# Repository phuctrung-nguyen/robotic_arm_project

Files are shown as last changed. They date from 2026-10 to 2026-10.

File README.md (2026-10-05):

# 4-DOF RPRR Welding Robot — Robotics Course Project

Design, analysis and simulation of a 4-degree-of-freedom welding robot arm of type **R–P–R–R** (revolute – prismatic – revolute – revolute), covering the full pipeline from mechanical design, kinematics, dynamics, trajectory planning and controller design to simulation in ROS 2.

## Contents

| Folder | Content | Tools |
|---|---|---|
| [`solid_des`](solid_des) | 3D models of the links, assemblies, welding head, technical drawings | SolidWorks |
| [`mapler`](maple) | Derivation of the robot's differential equations of motion | Maple |
| [`trajectory`](trajectory) | Forward/inverse kinematics (DH), Jacobian, workspace, manipulability index, LSPB trajectories in joint space and Cartesian space, animation | Python |
| [`IDPD_simulink`](IDPD_simulink) | IDPD (Inverse Dynamics PD) trajectory-tracking controller | MATLAB / Simulink |
| [`sim_ros2`](sim_ros2) | URDF model, Gazebo + RViz simulation, per-joint position control using Gazebo's PID | ROS 2 Jazzy, Gazebo Harmonic |

## Robot parameters (DH)

| Joint | Type | d (m) | a (m) | α (°) | Limits |
|---|---|---|---|---|---|
| q1 | Revolute | 0.2175 | 0 | 0 | 0° → 360° |
| q2 | Prismatic | q2 | 0.25 | 90 | 0 → 0.225 m |
| q3 | Revolute (θ = q3 + 90°) | 0.105 | 0 | 90 | −90° → 135° |
| q4 | Revolute (welding torch) | 0.262 | 0 | 0 | 0° → 360° |

Fixed base d0 = 0.084 m. The welding torch tip is offset by (−68, 0, 126) mm from frame O4.

End-effector convention: the workspace (`main.py`) is computed for the **welding torch tip** (with the offset above); the welding trajectory, inverse kinematics, Simulink and the ROS 2 simulation are all computed for the **origin of frame O4** (q4 = 0).

**Forward kinematics** (origin of frame O4):

```
x = 0.25·cos q1 + 0.105·sin q1 + 0.262·cos q1·cos q3
y = 0.25·sin q1 − 0.105·cos q1 + 0.262·sin q1·cos q3
z = q2 + 0.262·sin q3 + 0.3015
```

**Inverse kinematics**:

```
q1 = atan2(0.105, √(x² + y² − 0.105²)) + atan2(y, x)
q3 = atan2(√(1 − D²), D),   D = (x·cos q1 + y·sin q1 − 0.25) / 0.262
q2 = z − 0.262·sin q3 − 0.3015
```

This model is consistent across the whole repo: the DH table (`config/dh_params.yaml`), the URDF in ROS 2, the Python trajectory scripts and the Gazebo control node.

## Welding cycle

Non-contact arc welding along a 0.2 m vertical segment BA. The Cartesian trajectory uses a trapezoidal velocity profile (LSPB) with a sampling period of 0.01 s.

| Point | Coordinates (m) | Joint variables (q1 rad, q2 m, q3 rad) |
|---|---|---|
| HOME | (0.1518, −0.2730, 0.7698) | (−0.7205, 0.2101, 1.4013) |
| B — weld start | (0.1589, −0.1543, 0.7782) | (−0.2768, 0.2205, 1.7822) |
| A — weld end | (0.1589, −0.1543, 0.5782) | (−0.2768, 0.0205, 1.7822) |

| Phase | Max velocity | Acceleration | End time |
|---|---|---|---|
| HOME → B | 0.05 m/s | 0.10 m/s² | 2.88 s |
| Dwell at B (arc ignition) | — | — | 3.38 s |
| B → A (welding) | 0.01 m/s | 0.05 m/s² | 23.58 s |
| Dwell at A (crater filling) | — | — | 24.58 s |
| A → HOME | 0.05 m/s | 0.10 m/s² | 29.60 s |

2961 reference points in total (`Cartesian_Waypoints.txt`). The corresponding joint trajectories are exported to Simulink (`Vitridat.mat`, `Vantocdat.mat`, `Giatocdat.mat`).

## Quick start

**Kinematics & trajectories (Python)**

```bash
cd 03_dong_hoc_quy_dao_python
pip install -r requirements.txt
python main.py            # workspace + manipulability -> data/ket_qua.png
python JointSpace.py      # joint trajectories + export Vitridat/Vantocdat/Giatocdat.mat for Simulink
python CartesianSpace.py  # Cartesian trajectory + export Cartesian_Waypoints.txt
python animation.py       # 3D animation of the robot following the trajectory
python -m src.run_simulation  # quick Jacobian check at a sample configuration
```

**IDPD controller (MATLAB)**: run `initialize.m` first to load the parameters, then open `controller_simulation.slx` and click Run. See the [README](04_bo_dieu_khien_IDPD_simulink/README.md).

**ROS 2 simulation**: see [05_mo_phong_ros2/README.md](05_mo_phong_ros2/README.md).

## License

[MIT](LICENSE)

## Results

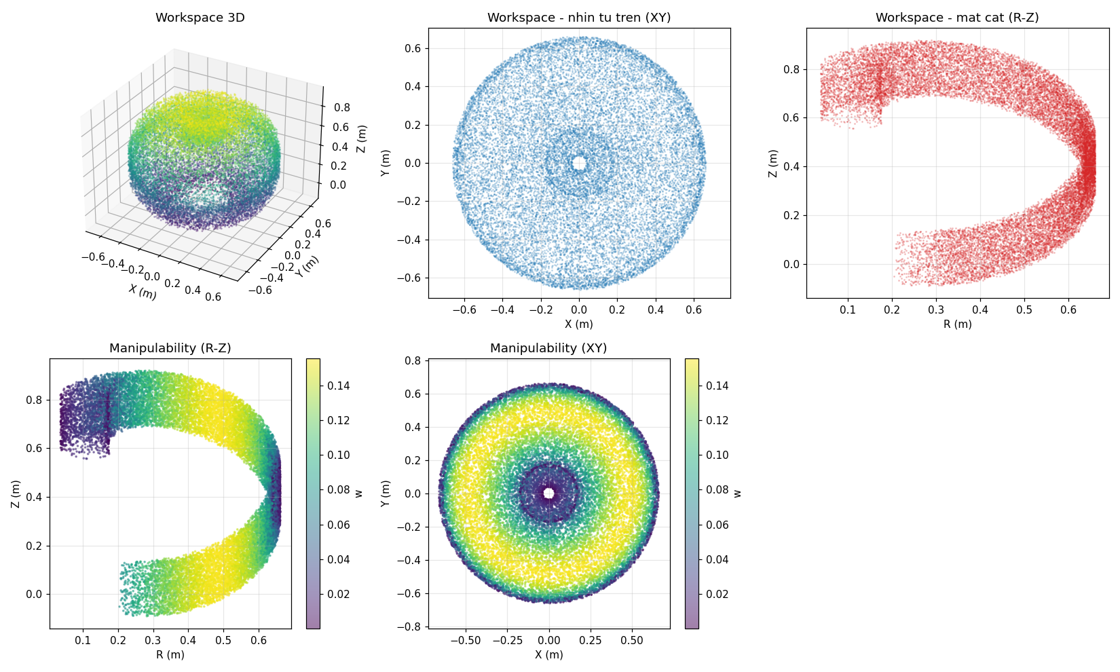
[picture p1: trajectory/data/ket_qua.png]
Workspace and manipulability


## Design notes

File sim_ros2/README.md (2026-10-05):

# Mô phỏng ROS 2 (Gazebo + RViz)

Workspace `rprr_ws` gồm 3 package:

```
rprr_ws/src/
├── robotic_arm_description/   # URDF/Xacro, mesh STL (xuất từ SolidWorks), cấu hình RViz
├── robotic_arm_bringup/       # Launch file, cấu hình Gazebo bridge
└── robotic_arm_control/       # trajectory_client.py: sinh quỹ đạo LSPB + động học ngược
```

## Yêu cầu

- Ubuntu 24.04 + ROS 2 Jazzy + Gazebo Harmonic (gz sim 8) — đã chạy thử trên cấu hình này
- **Không hỗ trợ ROS 2 Humble**: Humble đi kèm Gazebo Fortress, không nạp được các plugin `gz-sim-*` dùng trong
  `robotic_arm_gazebo.xacro` nên robot không có `/joint_states` và không điều khiển được
- `ros_gz_sim`, `ros_gz_bridge`, `robot_state_publisher`, `xacro`, `joint_state_publisher_gui`, `rviz2`
- Python: `numpy`

Cài các gói còn thiếu bằng `rosdep install --from-paths src --ignore-src -y` (trong `rprr_ws`).

## Build

```bash
cp -r rprr_ws ~/rprr_ws
cd ~/rprr_ws
colcon build
source install/setup.bash
```

## Chạy

Xem mô hình trên RViz (kéo thanh trượt để chỉnh từng khớp):

```bash
ros2 launch robotic_arm_bringup display.launch.py
```

Mô phỏng trên Gazebo + RViz:

```bash
ros2 launch robotic_arm_bringup gazebo.launch.py
```

Ở terminal thứ hai, chạy quỹ đạo hàn mẫu (Home → B → dừng → A → dừng → về Home):

```bash
cd ~/rprr_ws
source install/setup.bash
ros2 run robotic_arm_control trajectory_client.py
```

Quan sát Gazebo hoặc RViz, robot sẽ di chuyển theo đúng quỹ đạo đã thiết kế.

## Cách điều khiển trong Gazebo

`trajectory_client.py` tính trước quỹ đạo (LSPB trong không gian Cartesian + động học ngược) rồi cứ 10 ms phát
một điểm đặt xuống các topic `/q1_cmd_pos` ... `/q4_cmd_pos`. `ros_gz_bridge` chuyển các topic này sang Gazebo,
nơi mỗi khớp có một plugin `JointPositionController` (PID) riêng, khai báo trong
`robotic_arm_description/urdf/robotic_arm_gazebo.xacro`:

| Khớp | P | I | D |
|---|---|---|---|
| q1 | 12 | 0.2 | 1.0 |
| q2 | 120 | 80 | 20 |
| q3 | 300 | 200 | 4.0 |
| q4 | 15 | 0.3 | 1.5 |

Trạng thái khớp `/joint_states` do plugin `JointStatePublisher` của Gazebo phát và được bridge sang ROS 2 cho
RViz.

Trình tự chạy của node:

1. Chờ bản tin `/joint_states` đầu tiên để biết tư thế hiện tại của robot (lúc spawn là q = 0).
2. Đưa robot về HOME bằng đa thức bậc 3 trong không gian khớp (vận tốc đầu/cuối bằng 0, vận tốc đỉnh không quá
   50% giới hạn URDF), từ q = 0 mất khoảng 8.4 s.
3. Giữ tại HOME 1 s cho các bộ PID ổn định.
4. Chạy chu trình hàn 29.60 s (2961 điểm, trùng với `Vitridat.mat` của Simulink), xong thì node tự thoát.

Kết quả đo trong Gazebo: sai số vị trí gốc hệ O4 so với quỹ đạo đặt dưới 2 mm suốt chu trình, trung bình 0.1 mm
trên đoạn hàn B→A.

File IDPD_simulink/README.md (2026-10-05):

# Hướng dẫn chạy mô phỏng Simulink

Dự án này bao gồm mô hình Simulink và các tệp dữ liệu cần thiết. Để đảm bảo mô phỏng chạy chính xác, bạn vui lòng thực hiện đúng theo các bước sau:

## Các bước thực hiện

1. **Khởi tạo thông số (Quan trọng):**
   - Mở phần mềm MATLAB.
   - Điều hướng (Navigate) đến thư mục chứa các tệp dự án này.
   - Chạy tệp **`initialize.m`** bằng cách gõ lệnh sau vào Command Window hoặc click chuột phải vào file rồi chọn *Run*:
     ```matlab
     initialize
     ```
   - Bước này sẽ nạp các biến và tham số cần thiết vào *MATLAB Workspace*.

2. **Chạy mô hình Simulink:**
   - Sau khi đã chạy xong `initialize.m`, hãy mở tệp **`controller_simulation.slx`**.
   - Nhấn nút **Run** trong giao diện Simulink để bắt đầu mô phỏng.

---
**Lưu ý:** Nếu bạn không chạy `initialize.m` trước, mô hình Simulink sẽ báo lỗi do thiếu dữ liệu đầu vào hoặc tham số hệ thống chưa được định nghĩa.

## Dữ liệu quỹ đạo đặt

`Vitridat.mat`, `Vantocdat.mat`, `Giatocdat.mat` (vị trí, vận tốc, gia tốc khớp đặt; mỗi file 5 × 2961: hàng 0 là
thời gian, hàng 1–3 là q1..q3, hàng 4 là q4 = 0) được sinh bởi `03_dong_hoc_quy_dao_python/JointSpace.py`. Muốn đổi
quỹ đạo thì sửa script đó rồi chạy lại `python JointSpace.py`. Đây cũng chính là quỹ đạo mà node ROS 2
`trajectory_client.py` phát trong Gazebo.

- Robot xuất phát tại HOME: `initialize.m` đọc điểm đầu của `Vitridat.mat` vào biến `q_init`, dùng làm điều kiện đầu
  của khối tích phân `robot/qthuc`.
- Sau khi quỹ đạo kết thúc (29.60 s), các khối From File giữ nguyên vị trí cuối, vận tốc và gia tốc đặt bằng 0, nên
  robot đứng yên tại HOME tới hết thời gian mô phỏng (35 s).

## Kết quả mô phỏng

Với Kp = 500, Kd = 40 (MATLAB R2024a, solver ode45):

| Chỉ tiêu | Giá trị |
|---|---|
| Sai số khớp lớn nhất (0–35 s) | q1: 1.2·10⁻³ rad, q2: 0.23 mm, q3: 8.5·10⁻⁴ rad |
| Sai số mũi hàn lớn nhất | 0.25 mm (cả chu trình), 0.05 mm (đoạn hàn B → A) |
| Lực/mô-men điều khiển lớn nhất | q1: 0.13 N·m, q2: 35.4 N (chủ yếu giữ trọng lực), q3: 0.14 N·m |

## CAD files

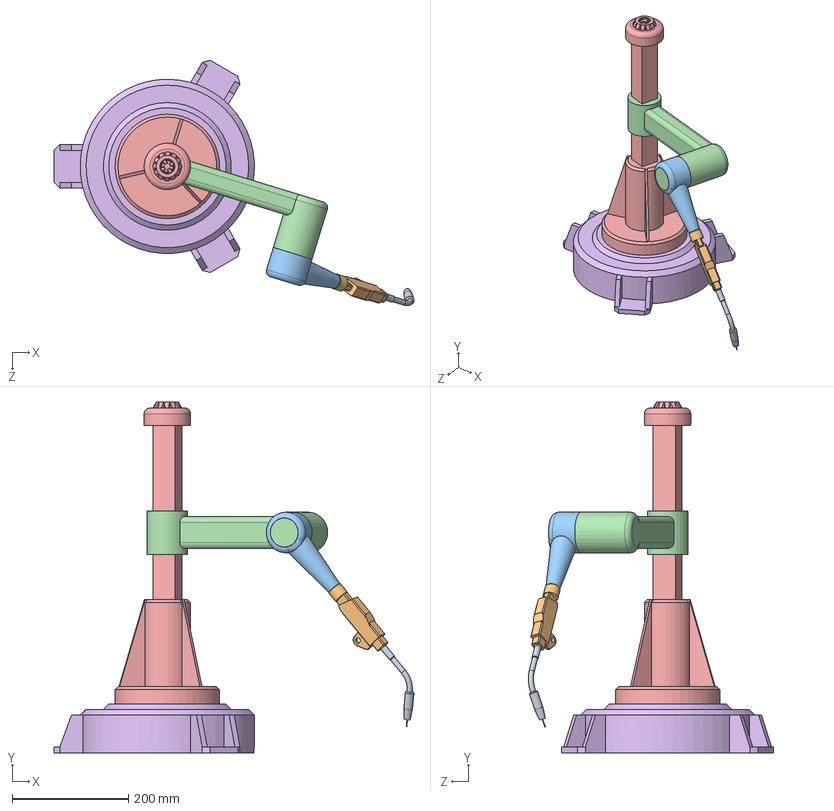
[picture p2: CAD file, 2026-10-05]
solid_design/robotic_assembly.SLDASM
620.2 x 604.0 x 422.9 mm
robotic_base
robotic_link1
robotic_link2
robotic_link3
robotic_link4
robotic_dau_han

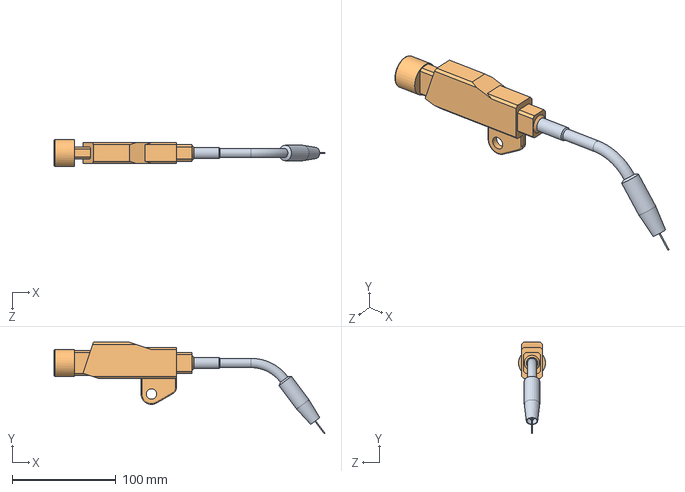
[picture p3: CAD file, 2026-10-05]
solid_design/robotic_endeffector_welding.SLDASM
261.4 x 88.3 x 26.0 mm
robotic_link4
robotic_dau_han

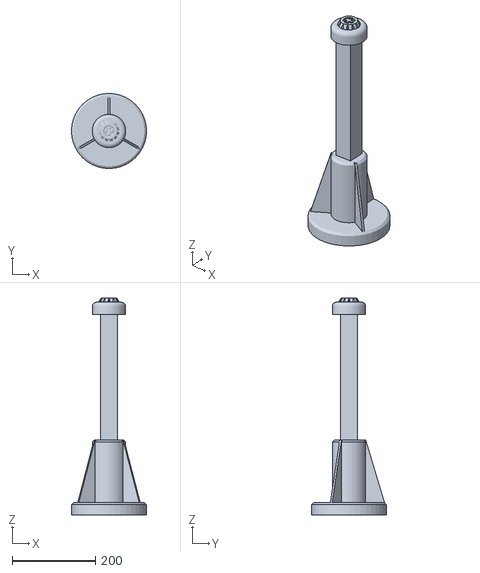
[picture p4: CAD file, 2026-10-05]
sim_ros2/rprr_ws/src/robotic_arm_description/meshes/robotic_link1.STL
180.0 x 180.0 x 520.0

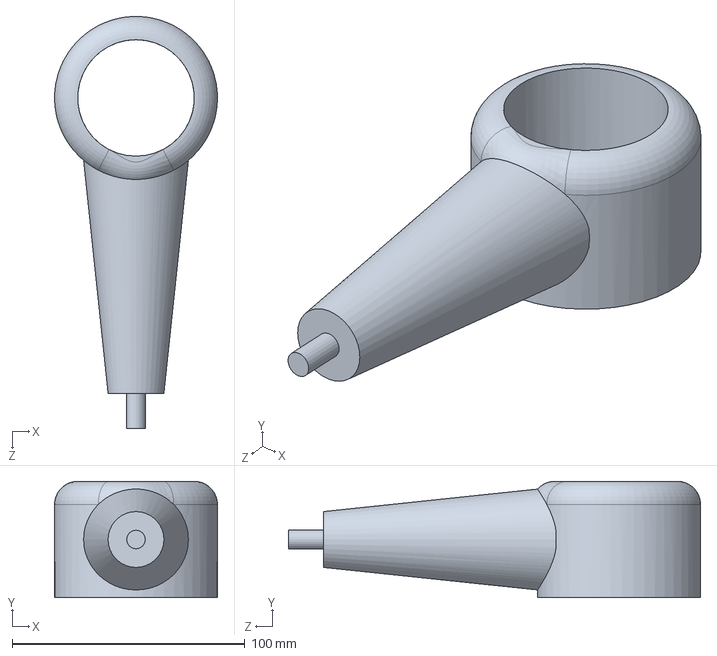
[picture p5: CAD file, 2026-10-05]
solid_design/robotic_link3.SLDPRT
70.0 x 50.0 x 177.0 mm

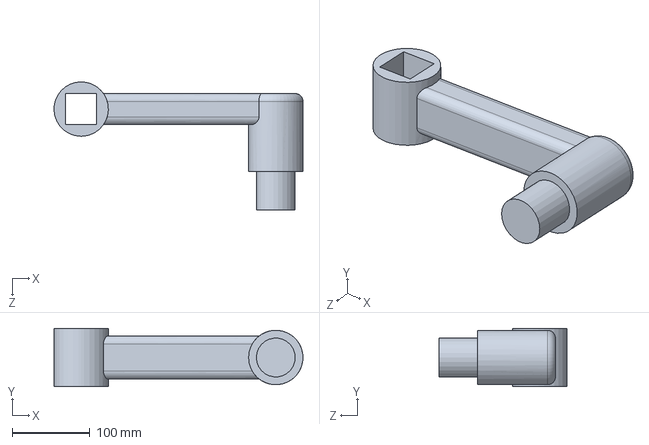
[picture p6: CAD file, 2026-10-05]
solid_design/robotic_link2.SLDPRT
320.3 x 75.0 x 165.0 mm

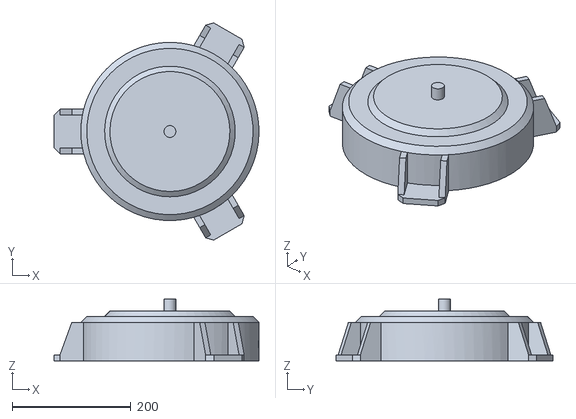
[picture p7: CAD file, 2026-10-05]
sim_ros2/rprr_ws/src/robotic_arm_description/meshes/robotic_base.STL
345.2 x 365.7 x 104.0

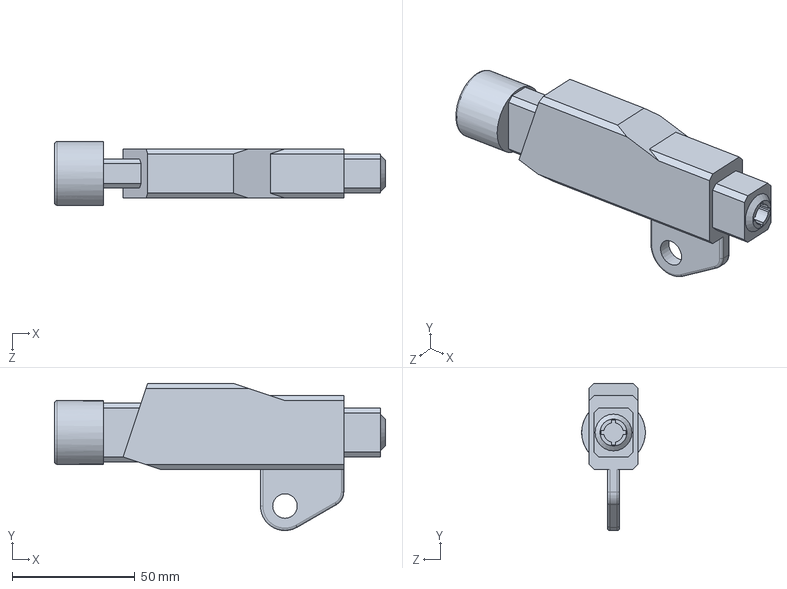
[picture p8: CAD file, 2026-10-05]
solid_design/robotic_link4.SLDPRT
135.0 x 60.0 x 26.0 mm

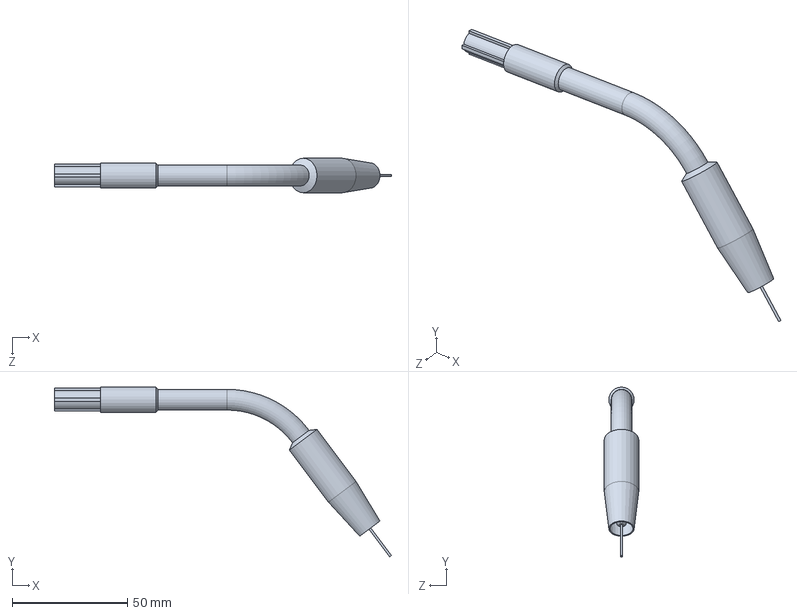
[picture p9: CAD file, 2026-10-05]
solid_design/robotic_dau_han.SLDPRT
146.4 x 73.8 x 15.0 mm

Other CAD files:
sim_ros2/rprr_ws/src/robotic_arm_description/meshes/robotic_link3.STL
sim_ros2/rprr_ws/src/robotic_arm_description/meshes/robotic_link2.STL
sim_ros2/rprr_ws/src/robotic_arm_description/meshes/robotic_endeffector_welding.STL
solid_design/robotic_link1.SLDPRT
solid_design/robotic_base.SLDPRT
solid_design/robotic_assembly.SLDDRW
solid_design/robotic_base.SLDDRW
solid_design/robotic_dau_han.SLDDRW
solid_design/robotic_endeffector_welding.SLDPRT
solid_design/robotic_link1.SLDDRW
solid_design/robotic_link2.SLDDRW
solid_design/robotic_link3.SLDDRW
solid_design/robotic_link4.SLDDRW

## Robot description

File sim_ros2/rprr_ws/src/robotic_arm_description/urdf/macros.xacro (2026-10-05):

<?xml version="1.0"?>
<robot xmlns:xacro="http://www.ros.org/wiki/xacro">

  <xacro:macro name="mesh_link_box" params="name mesh xyz rpy material scale mass com_xyz ixx ixy ixz iyy iyz izz collision_xyz:='0 0 0' collision_rpy:='0 0 0' collision_size:='0.01 0.01 0.01'">
    <link name="${name}">
      <visual>
        <origin xyz="${xyz}" rpy="${rpy}"/>
        <geometry>
          <mesh filename="${mesh}" scale="${scale}"/>
        </geometry>
        <material name="${material}"/>
      </visual>

      <collision>
        <origin xyz="${collision_xyz}" rpy="${collision_rpy}"/>
        <geometry>
          <box size="${collision_size}"/>
        </geometry>
      </collision>

      <inertial>
        <origin xyz="${com_xyz}" rpy="0 0 0"/>
        <mass value="${mass}"/>
        <inertia ixx="${ixx}" ixy="${ixy}" ixz="${ixz}" iyy="${iyy}" iyz="${iyz}" izz="${izz}"/>
      </inertial>
    </link>
  </xacro:macro>

  <xacro:macro name="mesh_link_cylinder" params="name mesh xyz rpy material scale mass com_xyz ixx ixy ixz iyy iyz izz collision_xyz:='0 0 0' collision_rpy:='0 0 0' collision_radius:='0.01' collision_length:='0.01'">
    <link name="${name}">
      <visual>
        <origin xyz="${xyz}" rpy="${rpy}"/>
        <geometry>
          <mesh filename="${mesh}" scale="${scale}"/>
        </geometry>
        <material name="${material}"/>
      </visual>

      <collision>
        <origin xyz="${collision_xyz}" rpy="${collision_rpy}"/>
        <geometry>
          <cylinder radius="${collision_radius}" length="${collision_length}"/>
        </geometry>
      </collision>

      <inertial>
        <origin xyz="${com_xyz}" rpy="0 0 0"/>
        <mass value="${mass}"/>
        <inertia ixx="${ixx}" ixy="${ixy}" ixz="${ixz}" iyy="${iyy}" iyz="${iyz}" izz="${izz}"/>
      </inertial>
    </link>
  </xacro:macro>

  <xacro:macro name="revolute_joint" params="name parent child xyz rpy axis lower upper effort velocity damping:=0.0 friction:=0.0">
    <joint name="${name}" type="revolute">
      <parent link="${parent}"/>
      <child link="${child}"/>
      <origin xyz="${xyz}" rpy="${rpy}"/>
      <axis xyz="${axis}"/>
      <limit lower="${lower}" upper="${upper}" effort="${effort}" velocity="${velocity}"/>
      <dynamics damping="${damping}" friction="${friction}"/>
    </joint>
  </xacro:macro>

  <xacro:macro name="prismatic_joint" params="name parent child xyz rpy axis lower upper effort velocity damping:=0.0 friction:=0.0">
    <joint name="${name}" type="prismatic">
      <parent link="${parent}"/>
      <child link="${child}"/>
      <origin xyz="${xyz}" rpy="${rpy}"/>
      <axis xyz="${axis}"/>
      <limit lower="${lower}" upper="${upper}" effort="${effort}" velocity="${velocity}"/>
      <dynamics damping="${damping}" friction="${friction}"/>
    </joint>
  </xacro:macro>

</robot>

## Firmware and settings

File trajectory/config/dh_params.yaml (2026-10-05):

# ============================================================
#  CAU HINH ROBOT HAN 4DOF  (R - P - R - R)
# ------------------------------------------------------------
#  Quy uoc DH: (theta, d, a, alpha)
#  - Goc (theta, alpha, limit cua khop quay) ghi bang DO -> code tu doi sang rad
#  - Chieu dai (d, a) va limit cua khop tinh tien ghi bang MET
# ============================================================

# Khau 0 - base co dinh (chi co d)
base_offset_d: 0.084        # m

# 4 khop. type: 'revolute' (bien la theta) | 'prismatic' (bien la d)
joints:
  - name: q1                # khop quay base
    type: revolute
    d: 0.2175               # m
    a: 0.0                  # m
    alpha: 0                # do
    theta_offset: 0         # do
    limit: [0, 360]         # do

  - name: q2                # khop tinh tien dung
    type: prismatic
    theta: 0                # do (co dinh)
    a: 0.25                 # m
    alpha: 90               # do
    d_offset: 0.0           # m
    limit: [0.0, 0.225]     # m

  - name: q3                # khop quay
    type: revolute
    d: 0.105                # m
    a: 0.0                  # m
    alpha: 90               # do
    theta_offset: 90        # do  ->  theta = q3 + 90
    limit: [-90, 135]       # do  (-pi/2 ... 3pi/4)

  - name: q4                # khop quay torch
    type: revolute
    d: 0.262                # m
    a: 0.0                  # m
    alpha: 0                # do
    theta_offset: 0         # do
    limit: [0, 360]         # do

# Toa do dau mo han trong he O4 (mm)
torch_offset_mm: [-68.0, 0.0, 126.0]

# So diem lay mau Monte Carlo
n_samples: 400000
